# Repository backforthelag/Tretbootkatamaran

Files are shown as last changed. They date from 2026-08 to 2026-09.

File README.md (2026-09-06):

# Tretbootkatamaran
Dieses Konstruktionsprojekt beinhaltet einen nicht vollständiges Model eines Tretbootkatamaranes. Bis auf die Sitze ist alles in Eigenfertigung erfolgt. Teils gibt es Probleme beim öffnen von Baugruppen, diese werden zukünftig noch behoben. Das öffnen ist zurzeit nur über Inventor (AutoCAD) möglich.

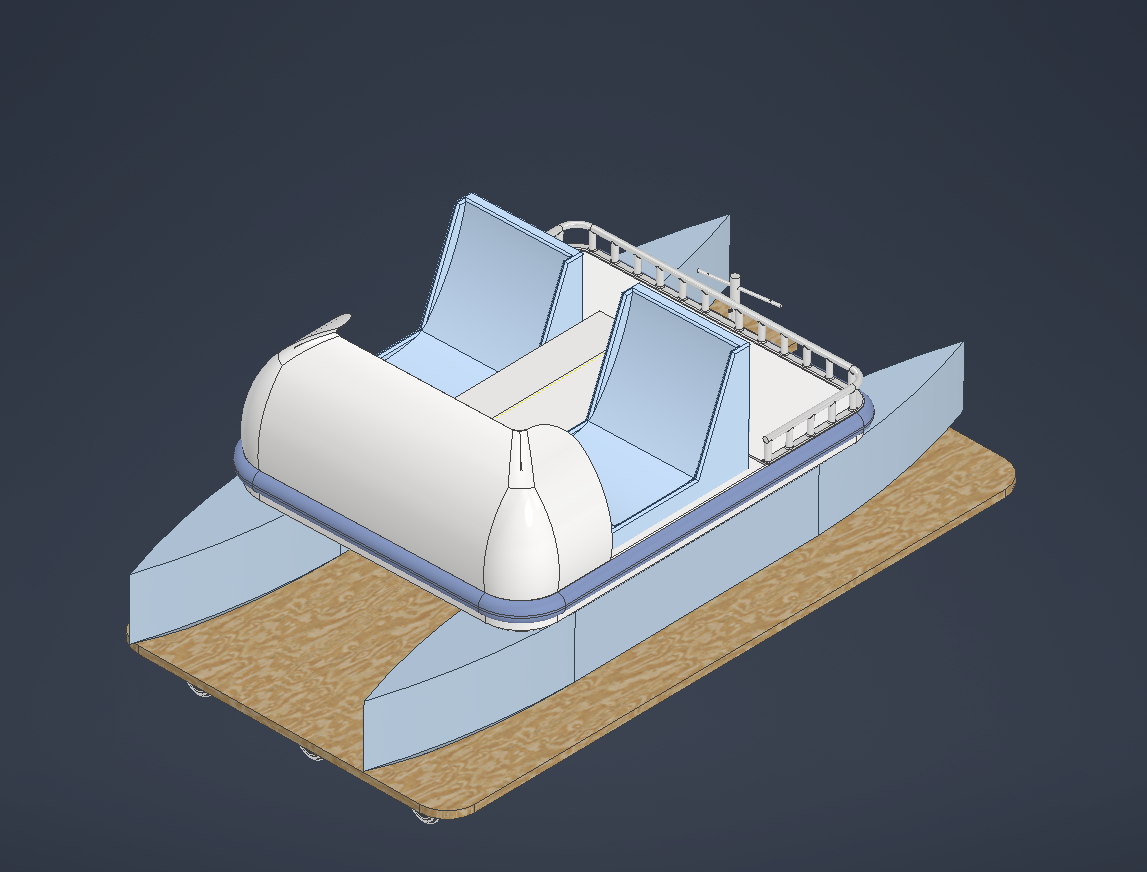
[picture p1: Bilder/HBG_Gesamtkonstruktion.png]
Bild: Hauptbaugruppe Tretbotkatamaran und Transportwagen


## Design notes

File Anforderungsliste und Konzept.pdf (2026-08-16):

### 1 A.Bunte

Bedienung

Lenkung über Schrauben, Lenkrad, Seilzug

## TretBoot-Katamaran

| Anforderungen
Kategorie | Bezeichnung der Eigenschaften | Quantitäts-wert | Qualitätswert | F/ W
Funktion | Transport von maximal 2 Personen über gemässigte Gewässer
Geometrie | Größe Höhe Breite Länge | 2,8qm <0,50m <1,6m <3,5m | Orientierung an Handelsüblichen Tretbooten, 2 Sitze symmetrisch nach vorne ausgerichtet | F
Kräfte | Gewichtskraft Drehmoment Pedal Drehmoment Schraube Auftriebskraft Antriebskraft | 2550N (≈260kg) 20-60Nm 20-60Nm 10-50Nm 10.954,23N 20-60Nm | Stabil, kippsicher, ausreichend Auftrieb auch bei Vollbelastung Gute Kraftübertragung vom Pedal auf den Antrieb Berechnet mit Polyethylendichte + 2 Personen à 70 kg | F
Kinematik | Bewegungsart Geschwindigkeit Beschleunigung | 5-10kmh | Schwimmen abhängig von Pedalkraft abhängig von der Pedalkraft | F
Energie | Leistung Reibung Wirkungsgrad | | abhängig vom Gesamtgewicht | F
Stoff | Schiffschraube Welle Pedal Außenhülle Sitze | 1 1-3 4 2 2 | leicht, groß, korrosionsbeständig recyclingfähig, Kummi Polyethyl (Standartkunststoff) Polyethylen | F
Signal | Signalform | | Navigationslichter, | F
Sicherheit | Sitz Halterung | 2 4 | rutschfest, stabile Sitzplätze kippstabil auch bei Gewichtsverlagerung | F
KT | Anforderungsliste | F = Forderung W = Wunsch
Auftrags-Nr.: | Projekt | Bearbeiter:

Ergonomie Beleuchtung Form
LED-Leuchte an der Front

### 2 parallele Rümpfe, verbunden durch Deck

F

Fertigung | Fertigungsverfahren Qualitäten Toleranzern | | Rotationssinter-Verfahren (PE-Granulat) | F
Kontrolle | Mess-und Prüfmöglichkeiten | | Prüfung von Materialermüdung, Dichtungen; Boot stabilisiert sich nach Slippen selbst | F
Montage | Vorschriftren Zusammenbau Aufbau | | gemäß Standards, sicherer Aufbau | F
Transport | Größe Gewicht Hilfsmittel | 0,5mx1,6mx3,5m 120Kg | Zugstange und Interrollen am Rumpf | F
Gebrauch | Geräuschentwicklung Einsatzort Verschleiß | <20db | abhängig von Geschwindigkeit nur für gemäßigte Gewässer Abnutzung an Rumpf und Kraftübertragungsteilen | F
Instandhaltung | Wartungsintervalle Reperatur Zeitbedarf | 30 Tage 2min | Überprüfung vor jedem Gebrauch Reparatur bei sichtbaren Schäden | F
Recycling | Wiederverwendung Verwertung Entsorgung | | Kunststoff kann geschreddert und als PE-Granulat wiederverwendet werden Fachgerechte Entsorgung, Recyclinghof | F
Kosten | Herstellerkosten Werkzeugkosten | <1000€ | kosteneffizient durch Standardteile und serientaugliche Fertigung | F
Termin | Liefertermin Projektplan | | Liefertermin nicht geplant, nur praktische Planung und theoretische Durchführung | F

# | Teilfunktionen

1 Muskelkraft in Drehmoment umwandeln 2 Drehmoment in Vortrieb wandeln 3 Richtung ändern 4 Personen aufnehmen 5 Trettboot transportieren 6 Trettboot montierten 7 Trettboot demontierten 8 Sicherheit gewährleisten 9 Befestigung zum sichern der Passagiere 10 Beleuchtung bereitstellen 11 Kollision lindern

Muskelkraft in Drehmoment umwandeln

Bewegungsenergie

Belastung

Verstellweg

Teile bewegen

Übertragung Kräfte

Rotationsenergie

Bewegung von Teilen

Rotationsbewegung

Drehmoment in Vortrieb wandeln

Rotationsenergie

Übertragung

Verstellweg

Teile bewegen

Übertragung Kräfte

hydrostatische Energie

Bewegung in Antriebsglied

Energie Antrieb

Richtung ändern

Kraftsteuerung

Übertragung

Verstellweg

Ruderstellung

Übertragung Kräfte

Bewegungsenergie

Bewegung Steuerungsstellglied Richtung

Energie Antrieb

Personen aufnehmen

Gewichtskraft

Verteilung

Verstellweg

Kraftübertragung
auf Material
Übertragung Kräfte

Druckenergie

Boot stabil

Halteenergie

Bootmaterial leitet Kräfte in Wasser

Trettboot transportieren

Zugkraft
Energie
wandeln

Steuerimpuls

Boot transportieren

Stoff leiten

Bewegungsenergie

Boot stabil

Ausführung der Bewegung

Bootmaterial leitet Kräfte in Wasser

Trettboot montieren

Bewegungsenergie
Energie
wandeln

Verbindung von
Bauteilen
Verknüpfung

Bewegungsenergie

Verbund aus Teilen

Boot

Trettboot demontieren

Körperkraft/ Werkzeugkraft

Hebekraft/ Stützkraft

Demontageanleitung

Trettboot montiert

Druckenergie / Reibungsenergie

Demontierte Komponenten

Demontage abgeschlossen

Verbindungen gelöst

Sicherheit gewährleisten

Handkraft / Muskelkraft

Handlungsanweisung

Gefahrensituation erkannt

Druckenergie / Halteenergie

Sicherheit gewährleistet

Sicherheitsbestätigung

Befestigung zum sichern der Passagiere

Handkraft

Sicherheitsvorgaben

Passagiere

Druckenergie / Halteenergie

gesicherte Passagiere

Sicherheitsbedingung erfüllt

Bauteile für Befestigung | geschlossene Befestigung

Beleuchtung bereitstellen

elektrische Energie

Signalfluss

Energie wandeln

Lichtwellen

Beleuchtung bereitgestellt

optischer energieflusss (Licht)

Kollision lindern

kinetische Energie

Kollision erkannt

Dämpfung gewährleisten

potentielle Enrgie

dämpfendes System

Risiko befälltigung

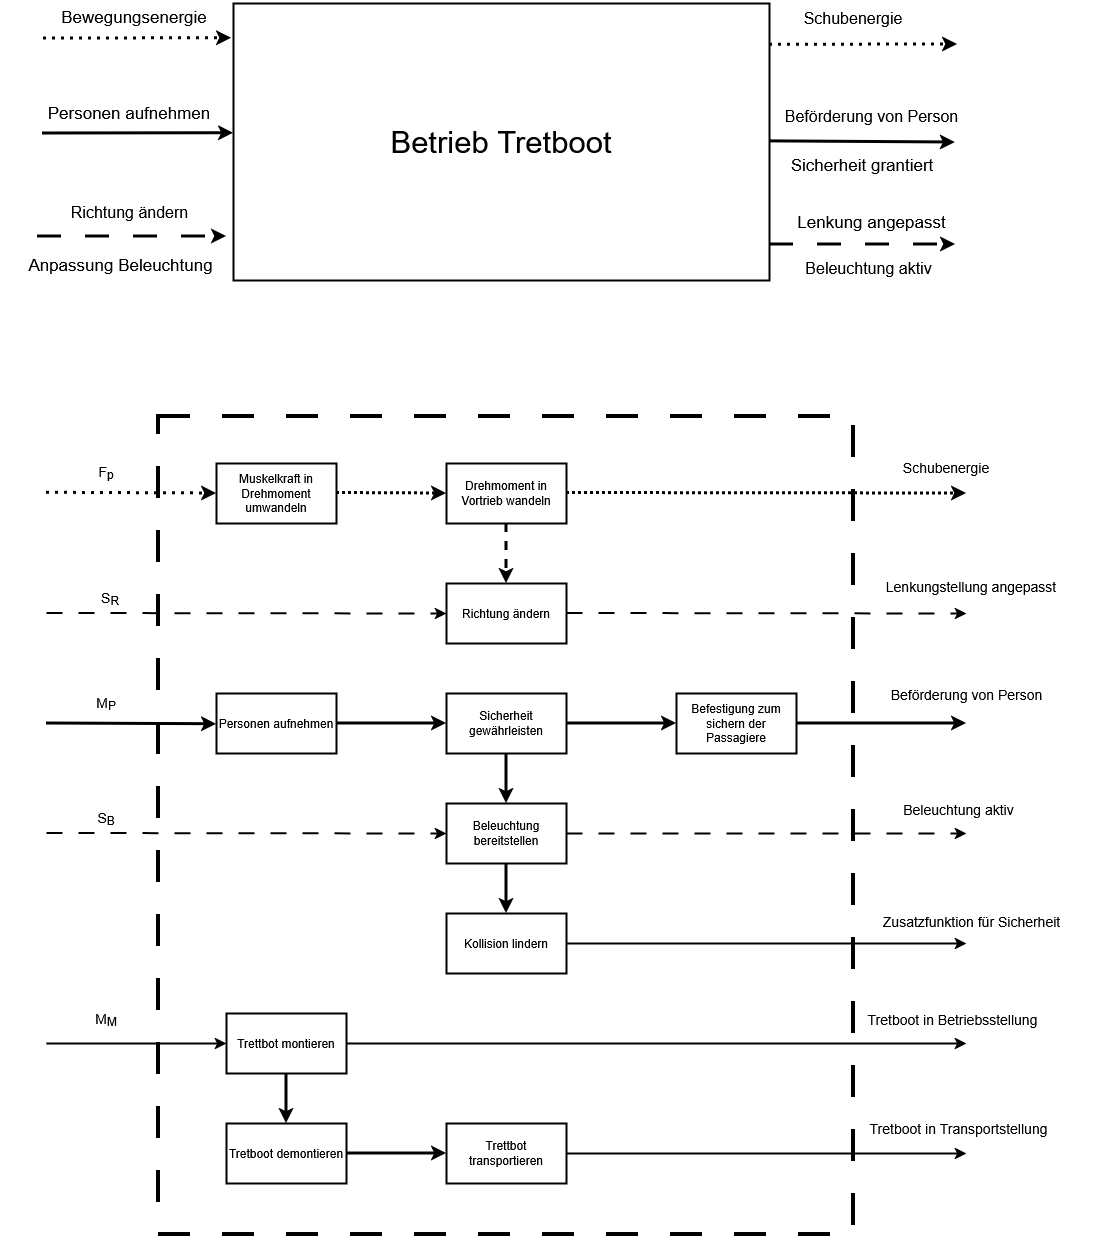
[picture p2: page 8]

Lösungen Teilfunktionen | 1 | 2 | 3 | 4
1 | Muskelkraft in Drehmoment umwandeln
2 | Drehmoment in Vortrieb wandeln | Zahnriemen | Rollenkette mit Spannrolle | Kardanwelle mit Kreuzgelenk | Riemenband
Kurbelpedal | Linear-Pedal mit Rückstellfeder | Pedalo-Mechanik | Doppelkurbel
3 | Richtung ändern | Ruderblatt mit Seilzuglenkung | Bugstrahler | Doppelruder über Stange | Strömungsleitblech hinter Propeller
4 | Personen aufnehmen | Sitzschale | Sitzschale mit Sitzkonsole(Schienenführung) Aluminiumbank mit Polster | Klappsitz mit Verrieglung
5 | Trettboot transportieren | Tragegriffe an den Seiten | Steckbare Transportrollen | Zugstange-Inter Rollen | 「 Rumpf-Rollen
6 | Trettboot montierten | Scharnier | Schnellspanner Exzenterklemme | Klappmechanismus Faltmodul | Verschraubung Flügelmuttern
7 | Trettboot demontierten | Splint Sicherung | Schiebeprofil | Bolzen mit Kontermutter | Scherengelenk
8 | Sicherheit gewährleisten | Rutschfeste Bodenmatte | Polster | Handlauf | Gummi Pedale
9 | Befestigung zum sichern der Passagiere
10 | Beleuchtung bereitstellen
Henkel | Boothandläufe | Reeling | Einstiegsleiter
LED-Positionslichter | Toplicht LED | Reflektorstreifen | LED-Leisten
10 | Kollision lindern | Scheuerleiste | Stoßfänger | Fender | Gummi Metall Puffer an Seiten

## Rot : Variante 1 Grün: Variante 2 Blau : Variante 3

、

Lösungen Teilfunktionen | 1 | 2 | 3 | 4
1 | Muskelkraft in Drehmoment umwandeln
2 | Drehmoment in Vortrieb wandeln
3 Richtung ändern | | | | | Strömungsleitblech hinter Propeller
4 | Personen aufnehmen | Sitzschale
5 | Trettboot transportieren | Tragegriffe
6 | Trettboot montierten | | | Klappmechanismus Faltmodul
7 | Trettboot demontierten | | | Bolzen mit Kontermutter
8 | Sicherheit gewährleisten | Rutschfeste Bodenmatte | Polster | Handlauf | Gummi Pedale
9 | Befestigung zum sichern der Passagiere | | | | Einstiegsleiter
10 | Beleuchtung bereitstellen
11 Kollision lindern | | | | | Gummi Metall Puffer an Seiten

Bewertungskriterien Eigenschaftsgrößen Nr. Gew. Einh. | Variante V Wert Gew. Wert | Variante V Wert Gew. Wert | Variante V Wert Gew.Wert
1 Tretboot ermöglicht Personentransport | | 0,05 zulässige Nutzlast | | kg | 5 | 0,25 | 3 | 0,15 | 4 | 0,2
2 Kapazität max. 2 personen | | 0,04 max. Personenzahl | | | 4 | 0,16 | 3 | 0,12 | 2 | 0,08
3 gute Manövrierbarkeit | | 0,12 min. Wenderadius | | | 3 | 0,36 | 2 | 0,24 | 2 | 0,24
4 Geschwindigkeit ausreichend für Freizeitbetrieb | | 0,06 Geschwindigkeit | | Kmh | 5 | 0,05 | 6 | 0,36 | 4 | 0,24
5 leichte Bedienbarkeit | | 0,12 erforderliche Tretkraft | | N | 6 | 0,14 | 3 | 0,36 | 1 | 0,12
6 gute Kraftübertragung | | 0,06 Wirkungsgrad | | % | 3 | 0,18 | 5 | 0,3 | 3 | 0,18
7 katamaranähnlicher Aufbau | | 0,05 Anzahl/ Abstand der Schwimmkörper Stück / m | | | 3 | 0,15 | 3 | 0,15 | 2 | 0,1
8 Wasserbeständigkeit | | 0,06 Material-Klasse | | | 5 | 0,3 | 3 | 0,18 | 4 | 0,24
9 Haltepunkte / Griffmöglichkeiten | | 0,04 Anzahl der Griffe | | Stück | 4 | 0,16 | 4 | 0,16 | 5 | 0,2
10 Höhe <0,5m | | 0,03 Gesamthöhe | | m | 3 | 0,09 | 3 | 0,09 | 1 | 0,03
11 Breite <1,6m | | 0,03 Gesamtbreite | | m | 3 | 0,09 | 3 | 0,09 | 3 | 0,09
12 Länge <3,5m | | 0,03 Gesamtlänge | | m | 3 | 0,09 | 2 | 0,06 | 3 | 0,09
13 Gewicht <140kg | | 0,05 Eigengewicht | | kg | 5 | 0,25 | 2 | 0,1 | 5 | 0,25
14 Betrieb auf Binnengewässern | | 0,05 Einsatzzweck-Klassifizierung | | | 4 | 0,2 | 3 | 0,15 | 4 | 0,2
15 Transport mit öffentlichen Verkehrsmitteln | | 0,12 max. Packmaße(LxBxH) | | m | 2 | 0,24 | 1 | 0,12 | 1 | 0,12
16 Produktionskosten <1000€ | | 0,09 Herstellungskosten, Stück | | € | 4 | 0,36 | 2 | 0,18 | 2 | 0,18
Summe | 1 | 3,07 | 2,81 | 2,56

Nutzwertanalyse Pkt. Bedeutung | Richtlinie VDI 2225 Pkt. Bedeutung
0 | absolut unbrauchbare Lösung | 0 | unbefriedigend
1 | sehr mangelhafte Lösung
2 | schwache Lösung | 1 | gerade noch tragbar
3 | tragbare Lösung
4 | ausreichende Lösung | 2 | ausreichend
5 | befriedigende Lösung
6 | gute Lösung mit geringen Mängeln | 3 | gut
7 | gute Lösung
8 | sehr gute Lösung | 4 | sehr gut (ideal)
9 | über die Zielvorstellung hinausgehende Lösung
10 | Ideallösung

Werteskala

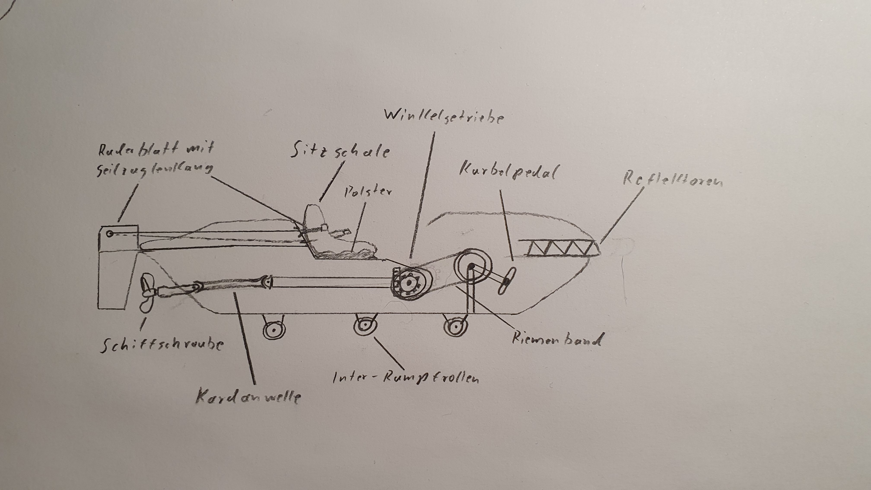
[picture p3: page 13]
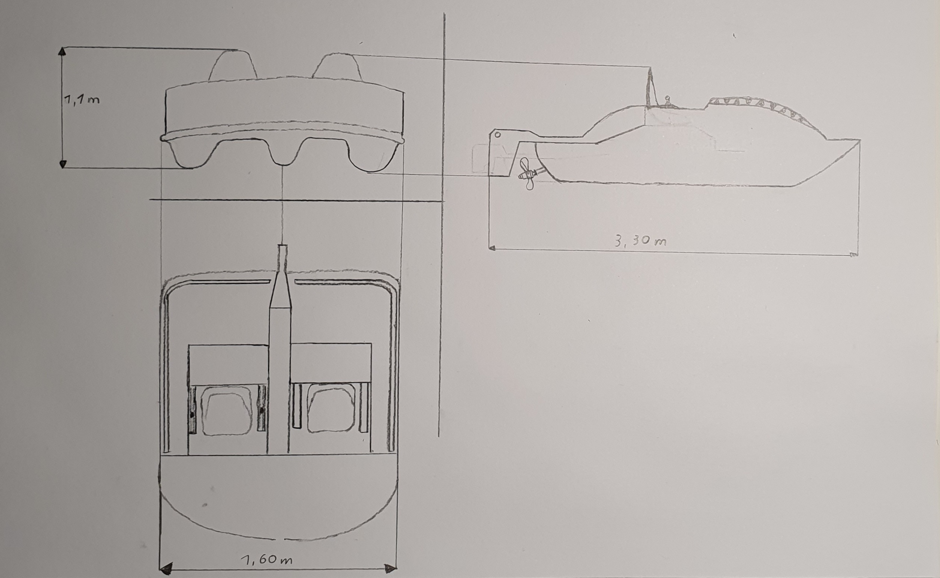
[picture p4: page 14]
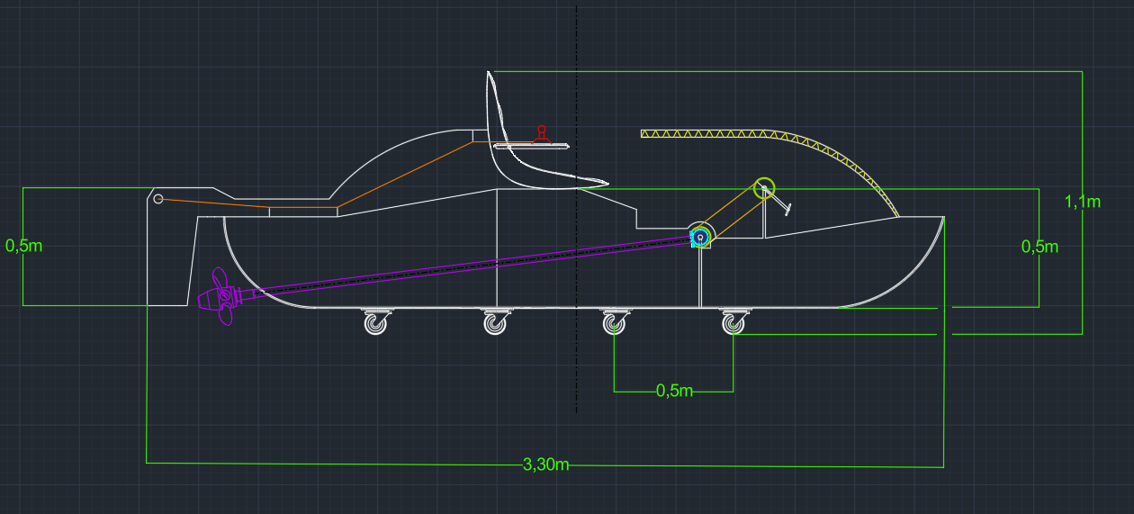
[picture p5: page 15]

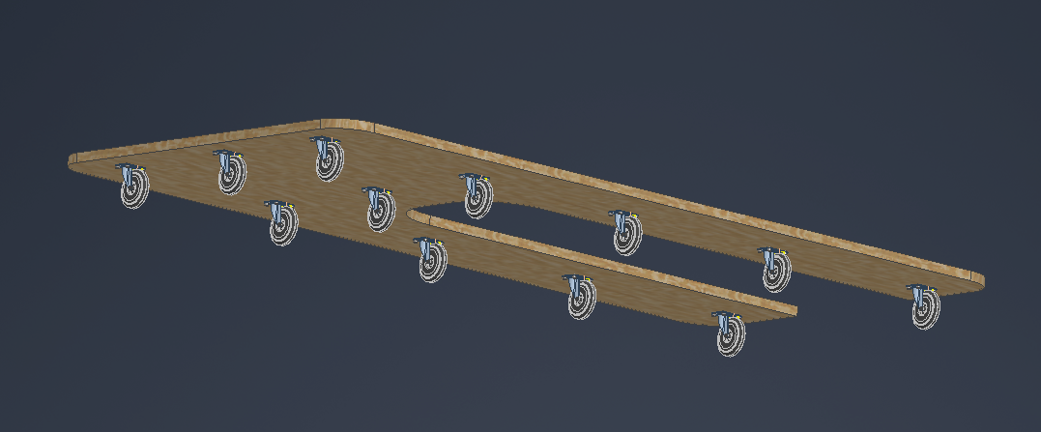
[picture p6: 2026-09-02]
Bilder/Transportwagen.png

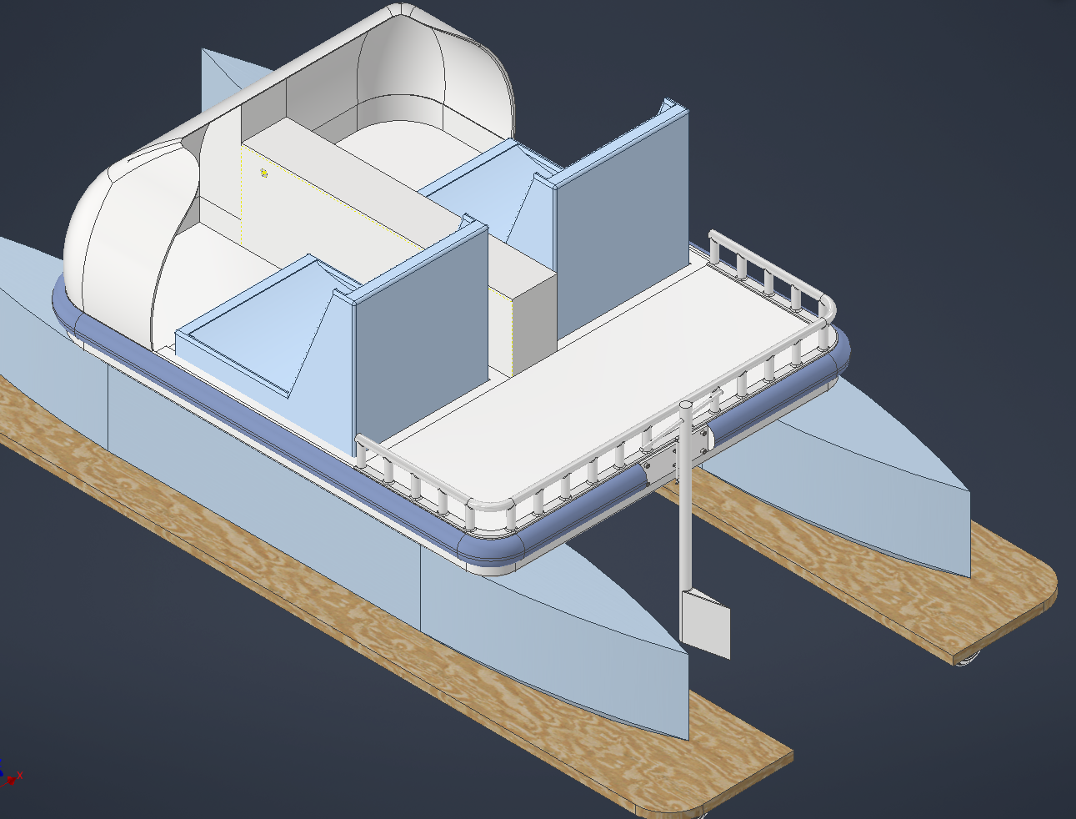
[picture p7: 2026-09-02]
Bilder/HBG_Rückseite.png

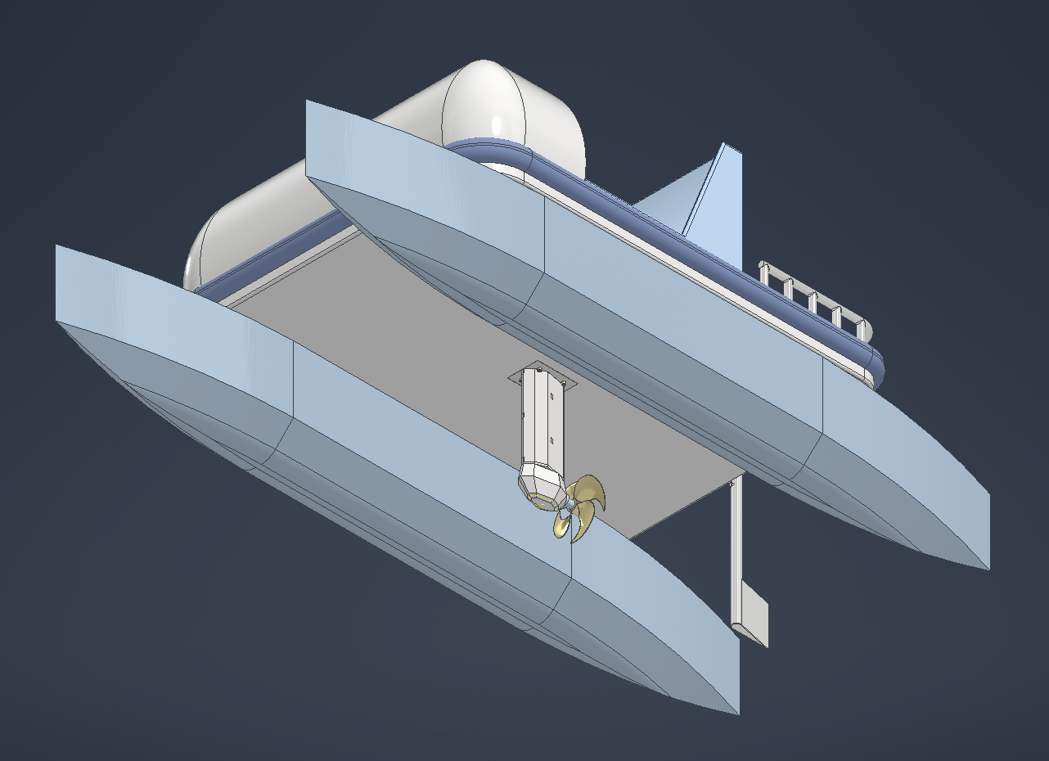
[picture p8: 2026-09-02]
Bilder/HBG_Unterseite.png

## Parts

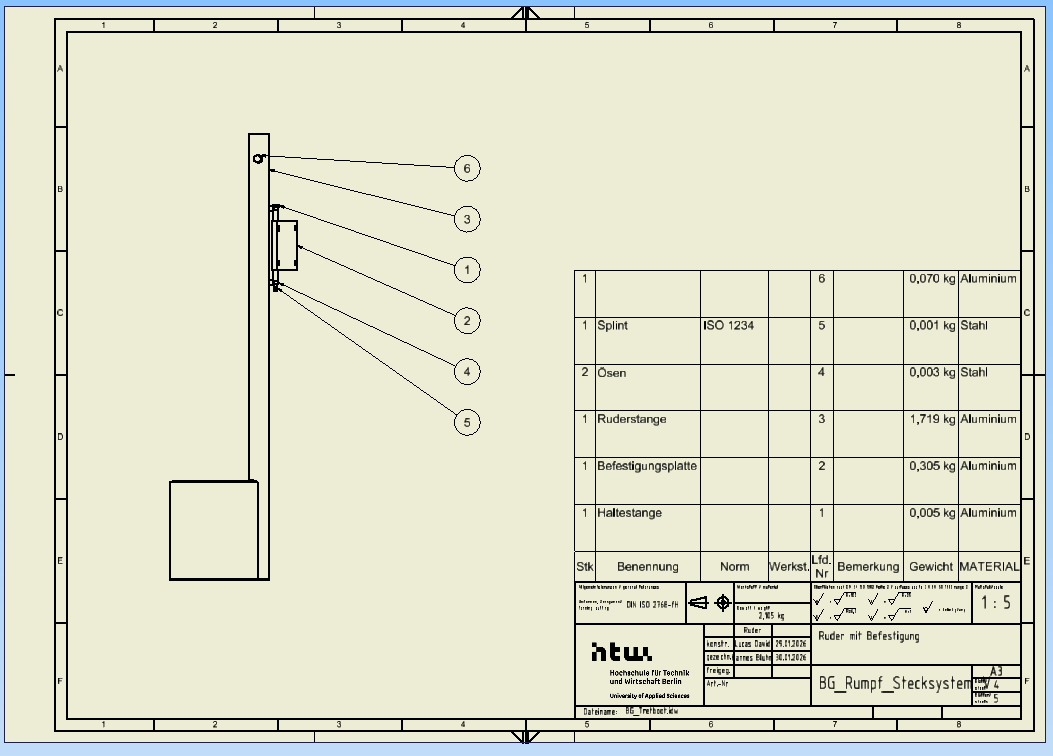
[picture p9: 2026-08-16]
Zeichnungen/Bilder Materialliste/Ruder.png

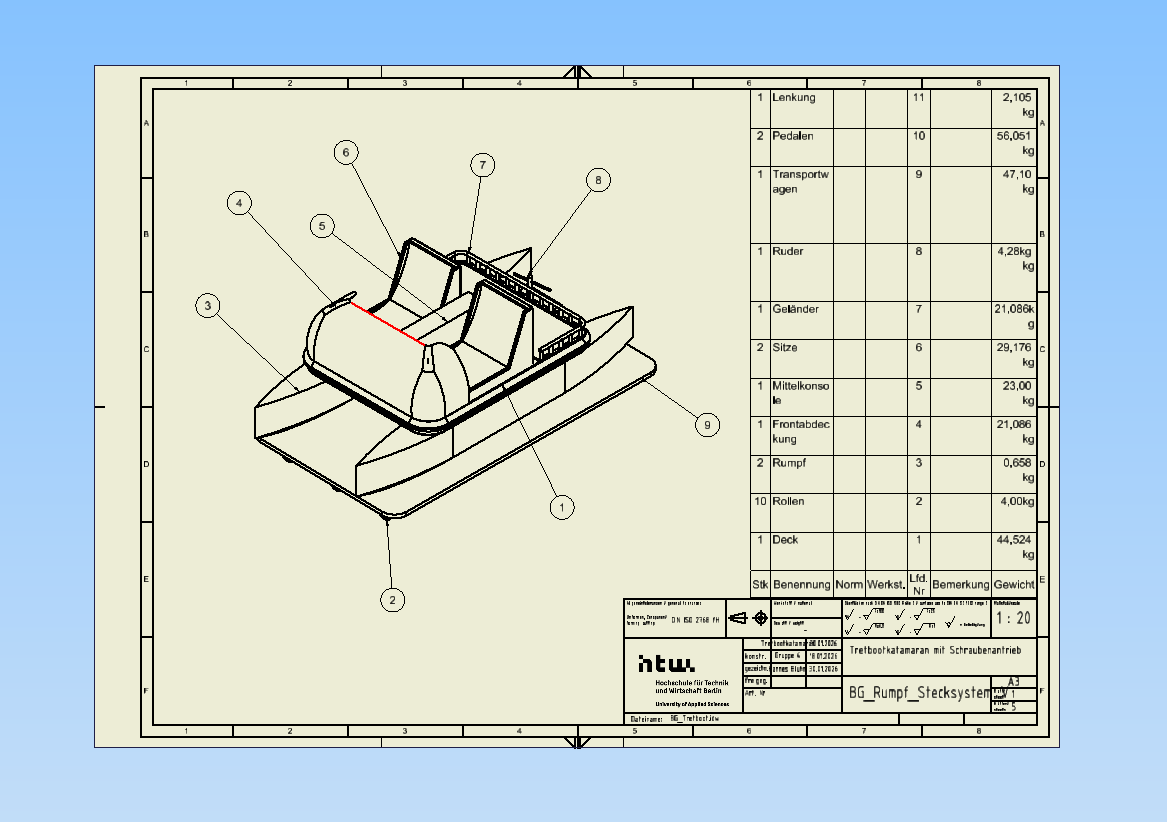
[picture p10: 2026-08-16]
Zeichnungen/Bilder Materialliste/Gesamtes_Tretboot.png

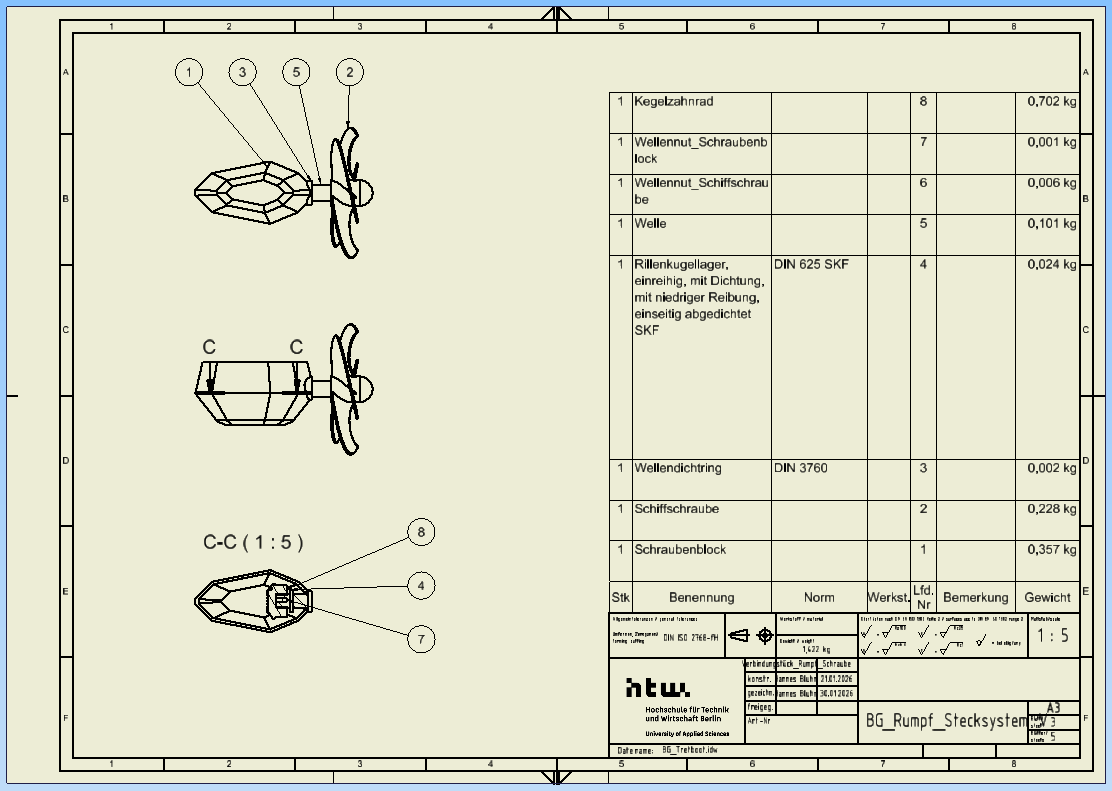
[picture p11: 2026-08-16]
Zeichnungen/Bilder Materialliste/Antrieb.png

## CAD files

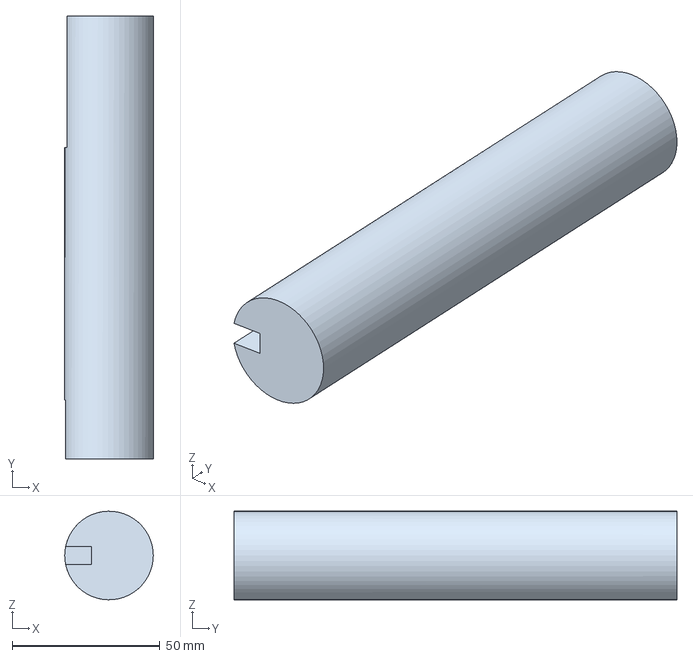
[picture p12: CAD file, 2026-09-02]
Step-Dateien/Antrieb/Welle_Schraube.stp
30.0 x 150.0 x 30.0 mm

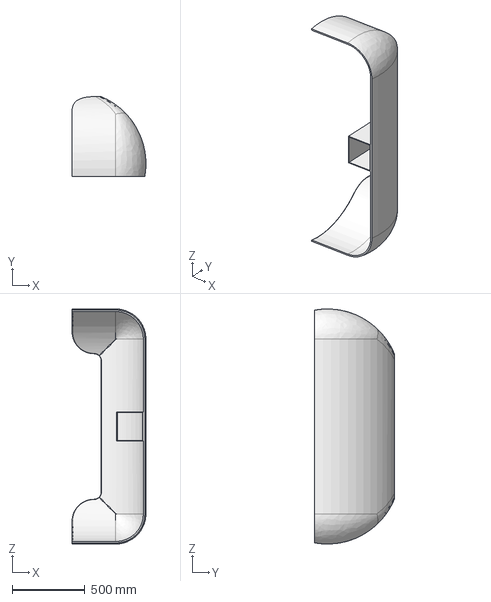
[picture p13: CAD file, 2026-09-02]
Step-Dateien/Deck/Frontabdeckung.stp
507.3 x 551.8 x 1615.1 mm

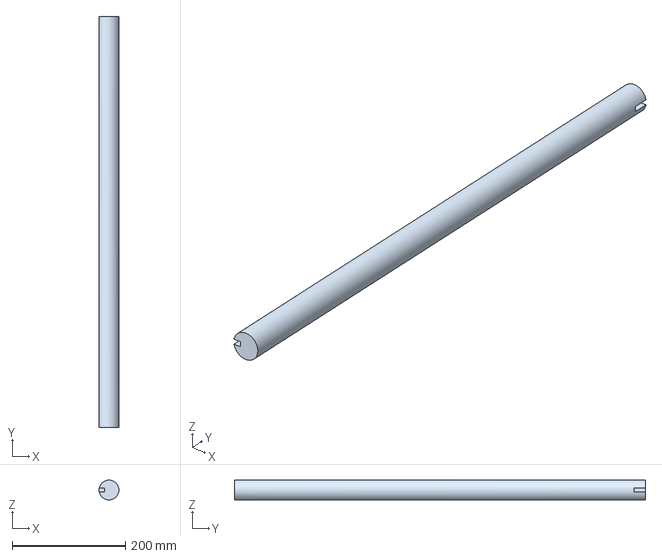
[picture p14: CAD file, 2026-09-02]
Step-Dateien/Deck_Getriebe/Welle_Deck_Getriebe.stp
35.0 x 724.3 x 35.0 mm

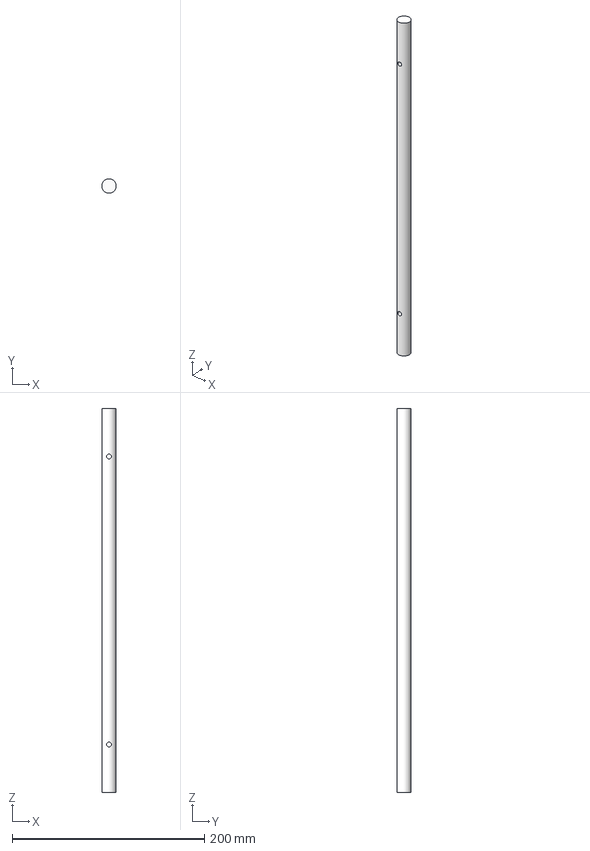
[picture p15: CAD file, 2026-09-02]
Step-Dateien/Ruder/Lenkstange.stp
15.0 x 15.0 x 400.0 mm

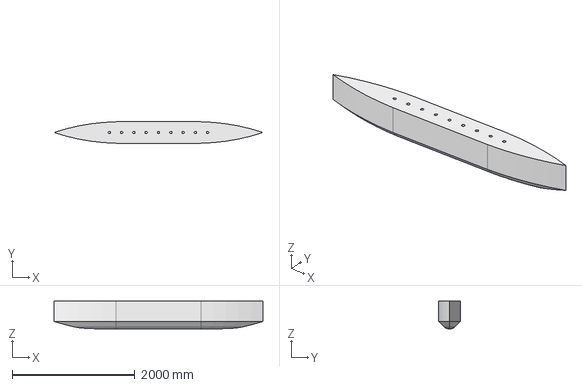
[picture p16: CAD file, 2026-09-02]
Step-Dateien/Rumpf/Außenrumpf_schnittig.stp
3400.0 x 350.0 x 450.0 mm

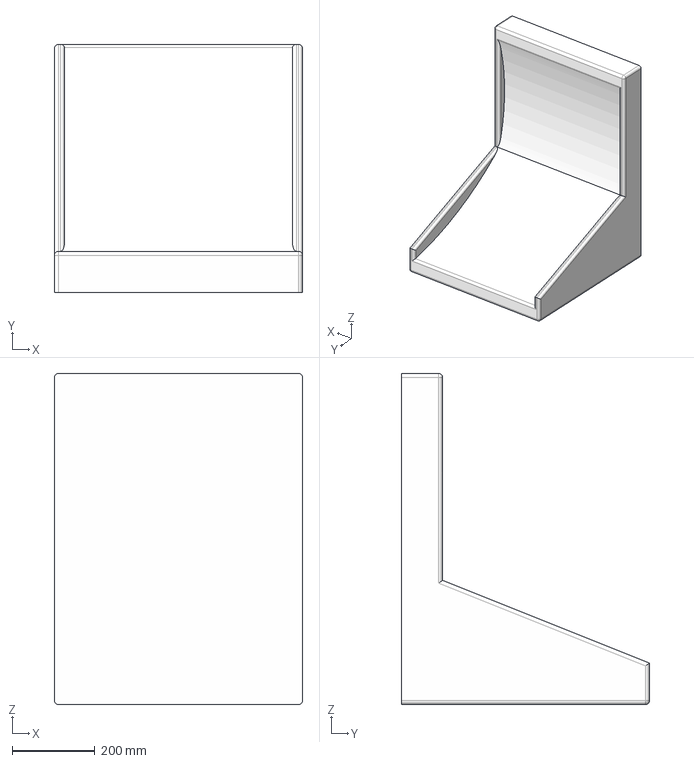
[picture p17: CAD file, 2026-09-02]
Step-Dateien/Sitz/Sitz.stp
600.0 x 600.0 x 800.0 mm

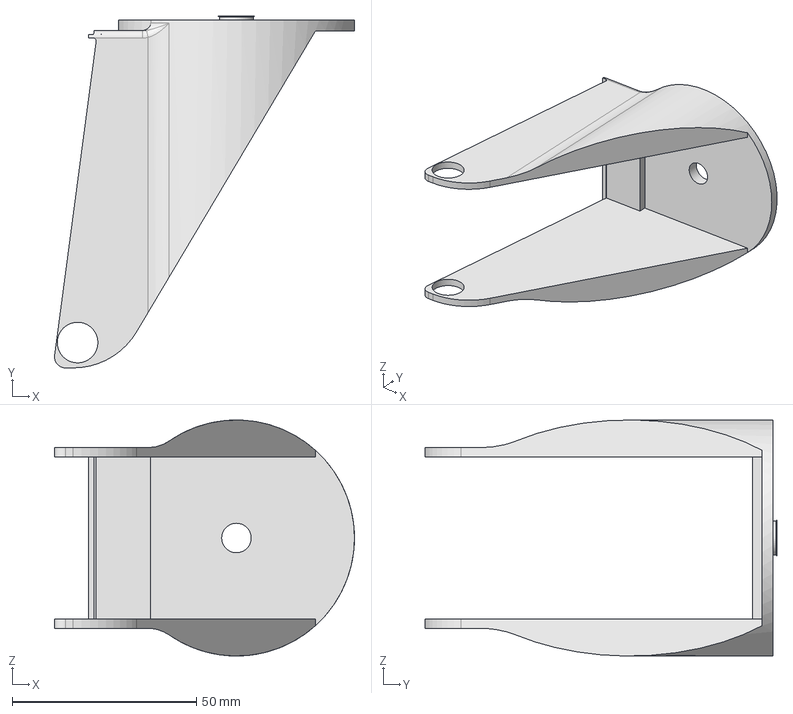
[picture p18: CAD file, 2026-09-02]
Step-Dateien/Transport/Rolle_RippenStütze.stp
81.3 x 95.4 x 64.0 mm

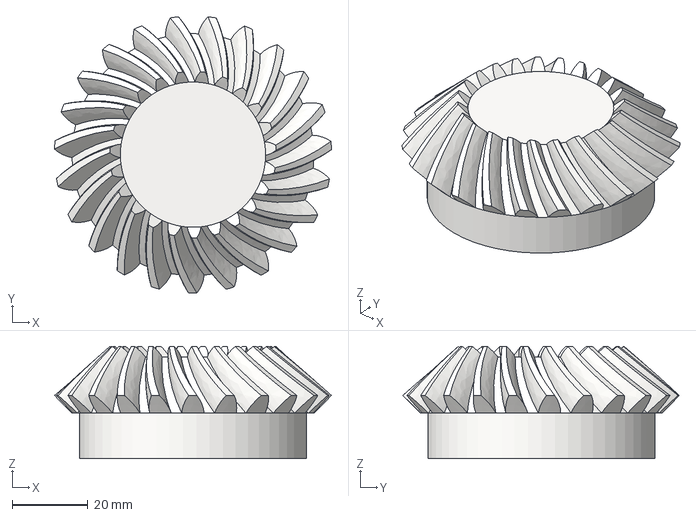
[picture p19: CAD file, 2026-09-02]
Step-Dateien/Verbindung_Deck_Antrieb/Kegelrad_20x10_01.stp
73.2 x 73.0 x 29.6 mm

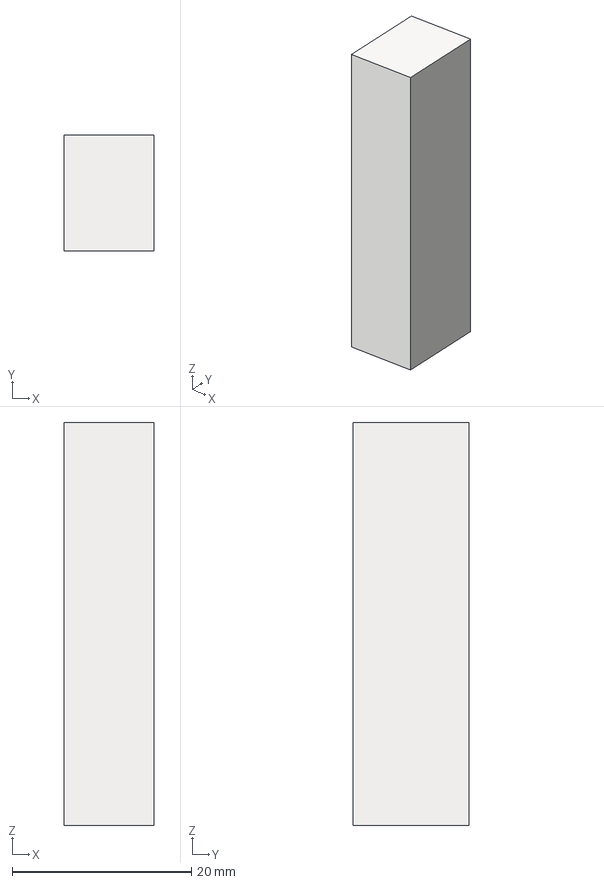
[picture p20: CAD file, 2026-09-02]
Step-Dateien/Antrieb/Wellennut_Antrieb_Propeller.stp
10.0 x 13.0 x 45.0 mm

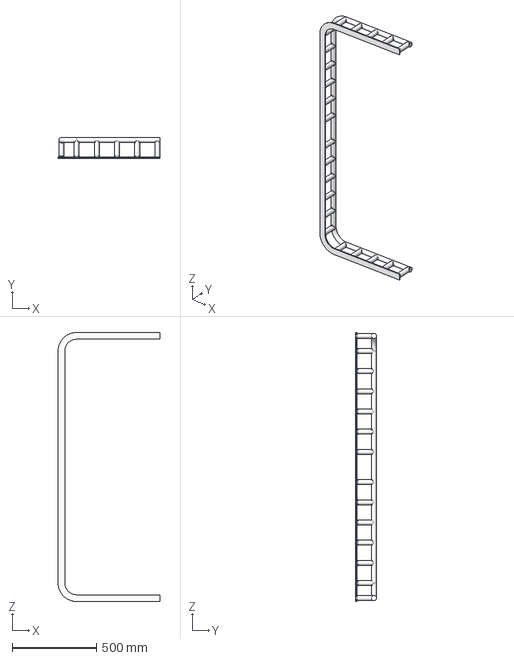
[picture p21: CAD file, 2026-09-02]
Step-Dateien/Deck/Geländer.stp
605.9 x 125.0 x 1600.0 mm

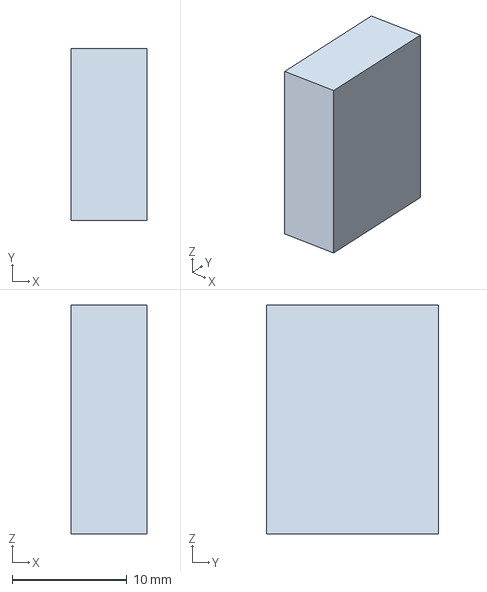
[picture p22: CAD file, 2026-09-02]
Step-Dateien/Deck_Getriebe/Wellennut.stp
6.62 x 15.0 x 20.0 mm

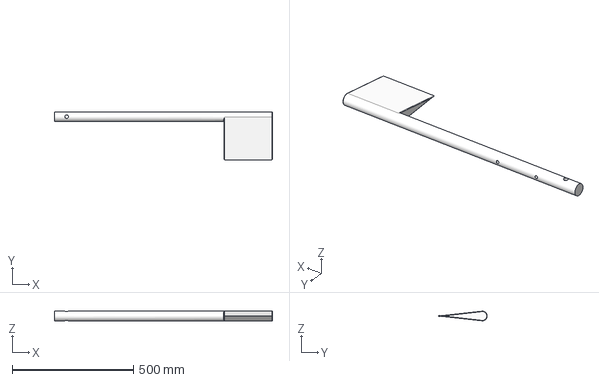
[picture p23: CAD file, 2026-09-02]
Step-Dateien/Ruder/Ruder_passende_Maße.stp
900.0 x 200.0 x 40.0 mm

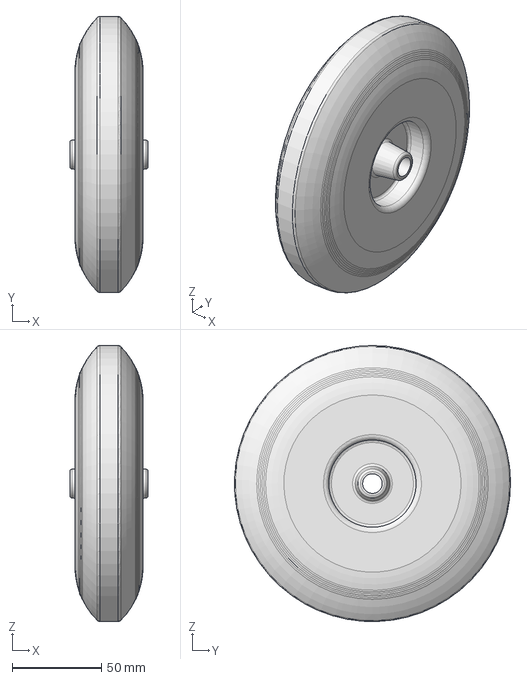
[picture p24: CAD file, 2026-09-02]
Step-Dateien/Transport/Rolle.stp
44.0 x 154.9 x 154.9 mm

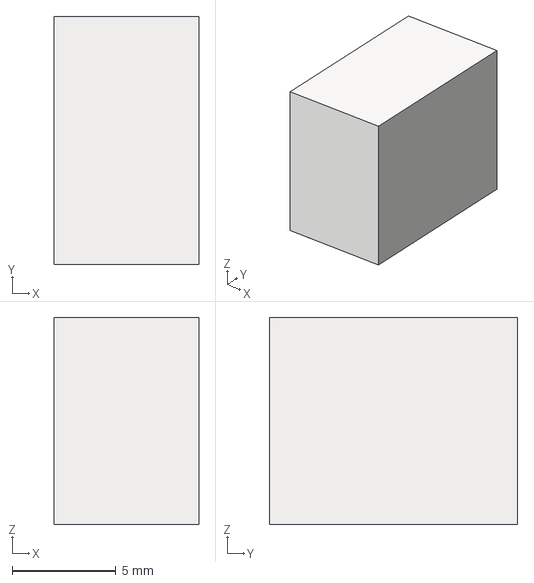
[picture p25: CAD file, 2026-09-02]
Step-Dateien/Verbindung_Deck_Antrieb/Wellennut_Verbindung_Deck_Antrieb.stp
7.00 x 12.0 x 10.0 mm

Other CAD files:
Step-Dateien/Antrieb/Propeller_groß.stp
Step-Dateien/Deck/Verbindungsstück_Rumpf_Stecksystem.stp
Step-Dateien/Deck_Getriebe/Mittelkonsole.stp
Step-Dateien/Ruder/Plattform_mit_Rohr_für_Montierung.stp
Antrieb/BG_Schiffschraube.iam
Antrieb/Kegelrad01.ipt
Antrieb/OldVersions/BG_Schiffschraube.0010.iam
Antrieb/Propeller.ipt
Antrieb/Propeller_groß.ipt
Antrieb/Schrauben_Block.ipt
Antrieb/Schrauben_Strang.ipt
Antrieb/Welle_Schraube.ipt
Antrieb/Wellennut_Antrieb_Propeller.ipt
Antrieb/Wellennut_Antrieb_Schrauben_Block.ipt
Deck/Frontabdeckung.ipt
Deck/Geländer.ipt
Deck/Verbindungsstück_Rumpf_Stecksystem.ipt
Deck_Getriebe/BG_Kegelräder.iam
Deck_Getriebe/BG_Kegelzahnräder.iam
Deck_Getriebe/BG_Mittelkonsole.iam
Deck_Getriebe/Kegelrad01.ipt
Deck_Getriebe/Kegelrad02.ipt
Deck_Getriebe/Mittelkonsole.ipt
Deck_Getriebe/Neu Kegelrad_Version01.ipt
Deck_Getriebe/Neu Kegelrad_Version02.ipt
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

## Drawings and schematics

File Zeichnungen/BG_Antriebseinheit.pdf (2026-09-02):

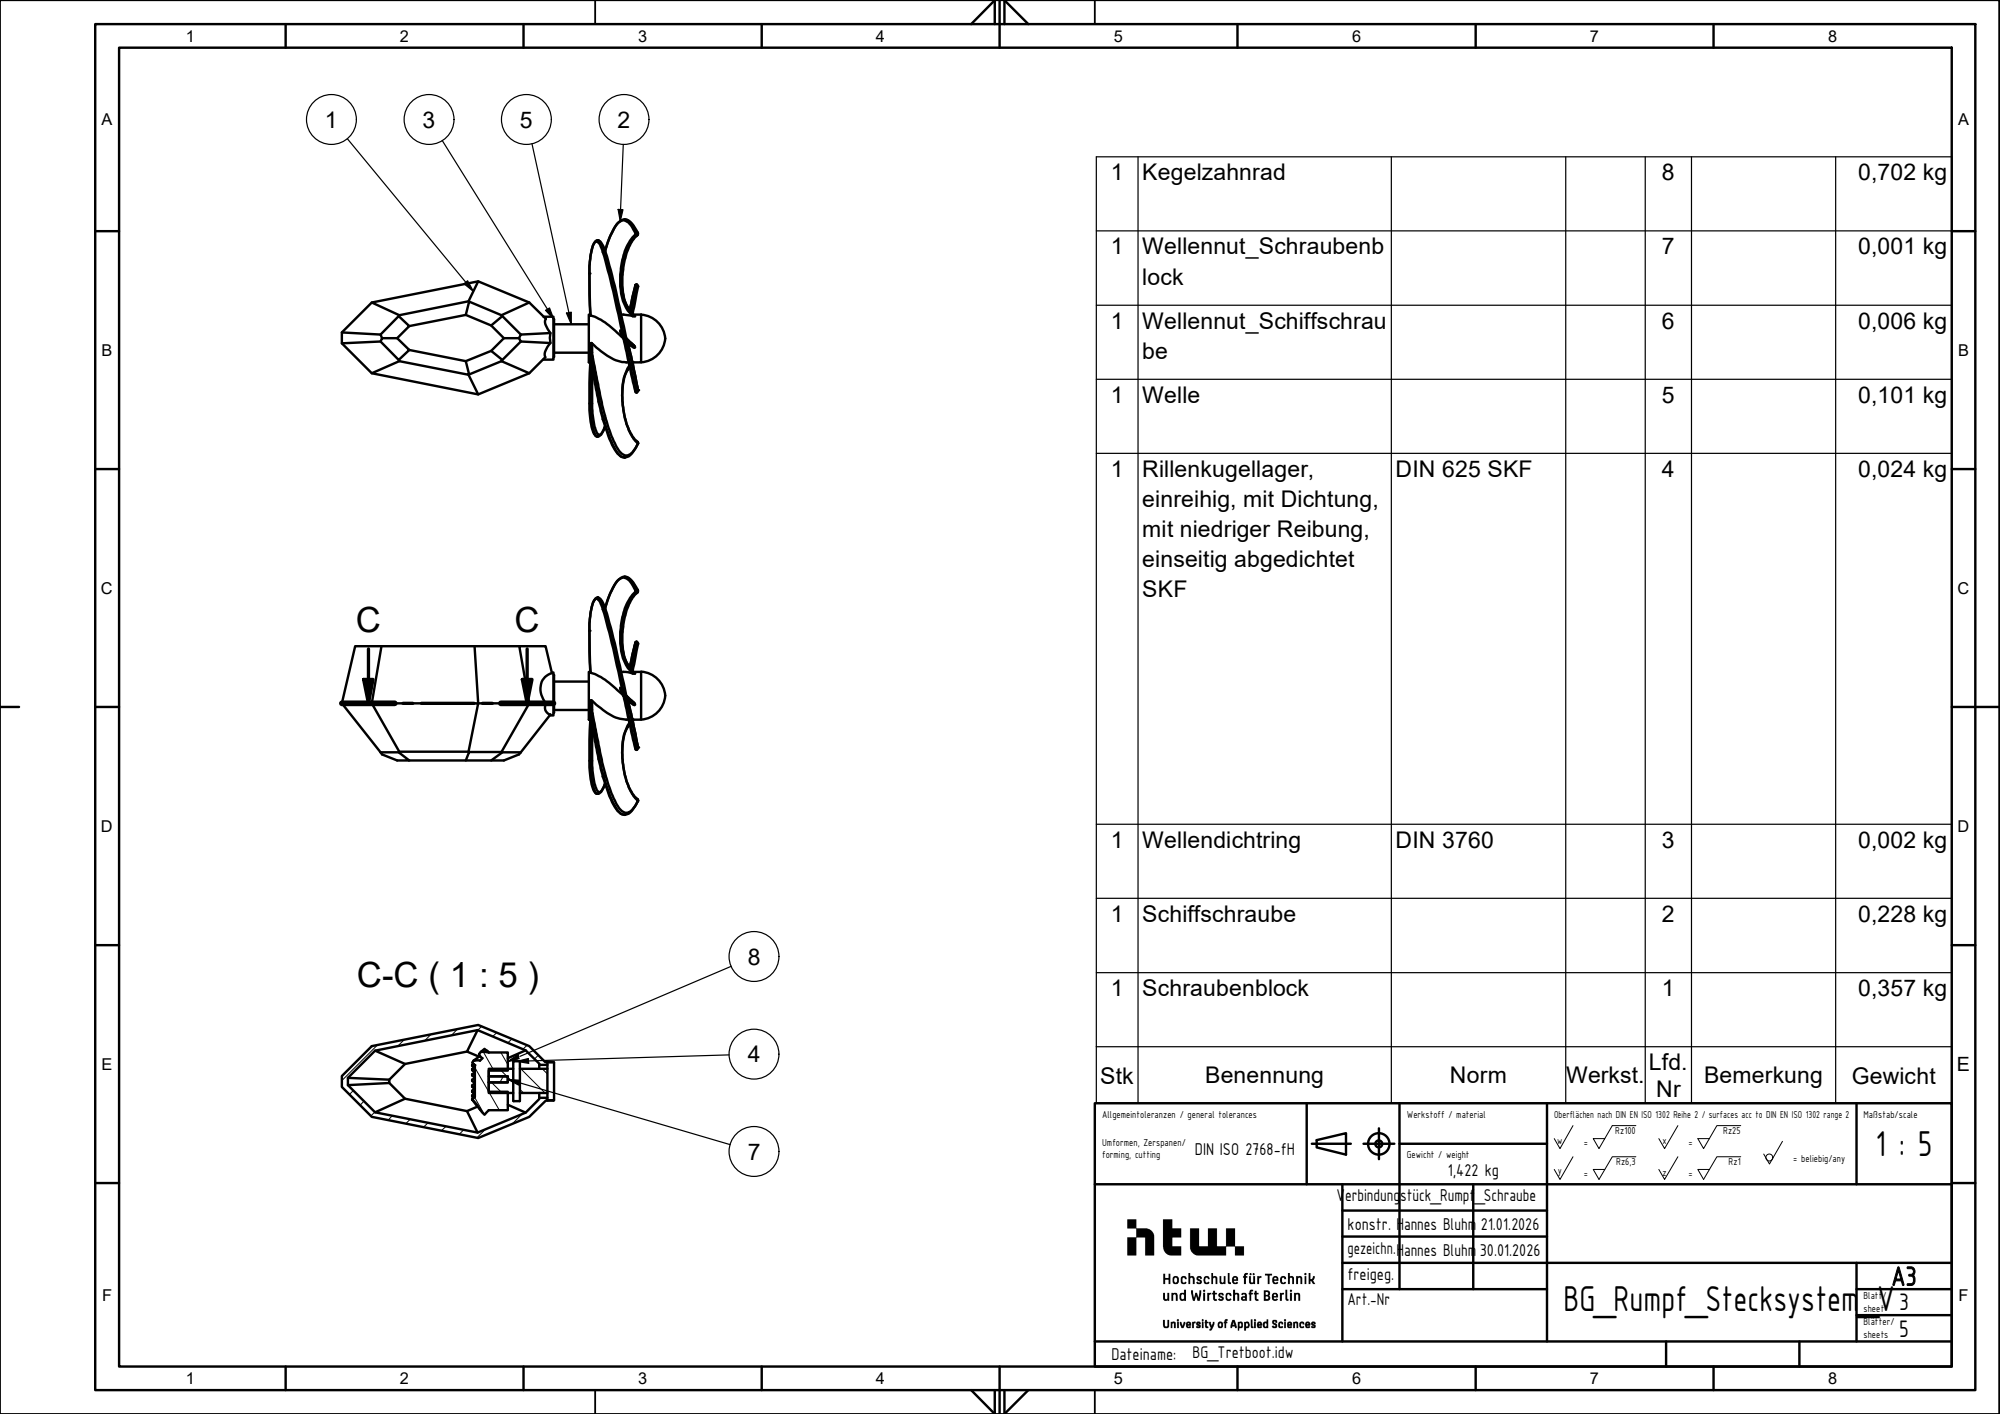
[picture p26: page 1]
Gewicht / weight 1,422 kg; Dateiname: BG_Tretboot.idw

1 | Kegelzahnrad | | | 8 | | 0,702 kg

1 | Wellennut_Schraubenb lock | | | 7 | | 0,001 kg

1 | Wellennut_Schiffschrau be | | | 6 | | 0,006 kg

1 | Welle | | | 5 | | 0,101 kg

1 | Rillenkugellager, einreihig, mit Dichtung, mit niedriger Reibung, einseitig abgedichtet SKF | DIN 625 SKF | | 4 | | 0,024 kg

1 | Wellendichtring | DIN 3760 | | 3 | | 0,002 kg

1 | Schiffschraube | | | 2 | | 0,228 kg

1 | Schraubenblock | | | 1 | | 0,357 kg

Stk | Benennung | Norm | Werkst. | Lfd. Nr | Bemerkung | Gewicht

Allgemeintoleranzen / general tolerances Umformen, Zerspanen/ forming, cutting DIN ISO 2768-fH | | Werkstoff / material | Oberflächen nach DIN EN ISO 1302 Reihe 2 / surfaces acc to DIN EN ISO 1302 range 2 Rz100 Rz25 w = x = = beliebig/any Rz6,3 Rz1 y = z = | Maßstab/scale 1 : 5

Verbindungstück_Rumpf_Schraube
konstr. | Hannes Bluhm | 21.01.2026
gezeichn. | Hannes Bluhm 30.01.2026
freigeg. | | | BG_Rumpf_Stecksystem_V | A3
Art.-Nr | | | | Blatt/ 3 sheet

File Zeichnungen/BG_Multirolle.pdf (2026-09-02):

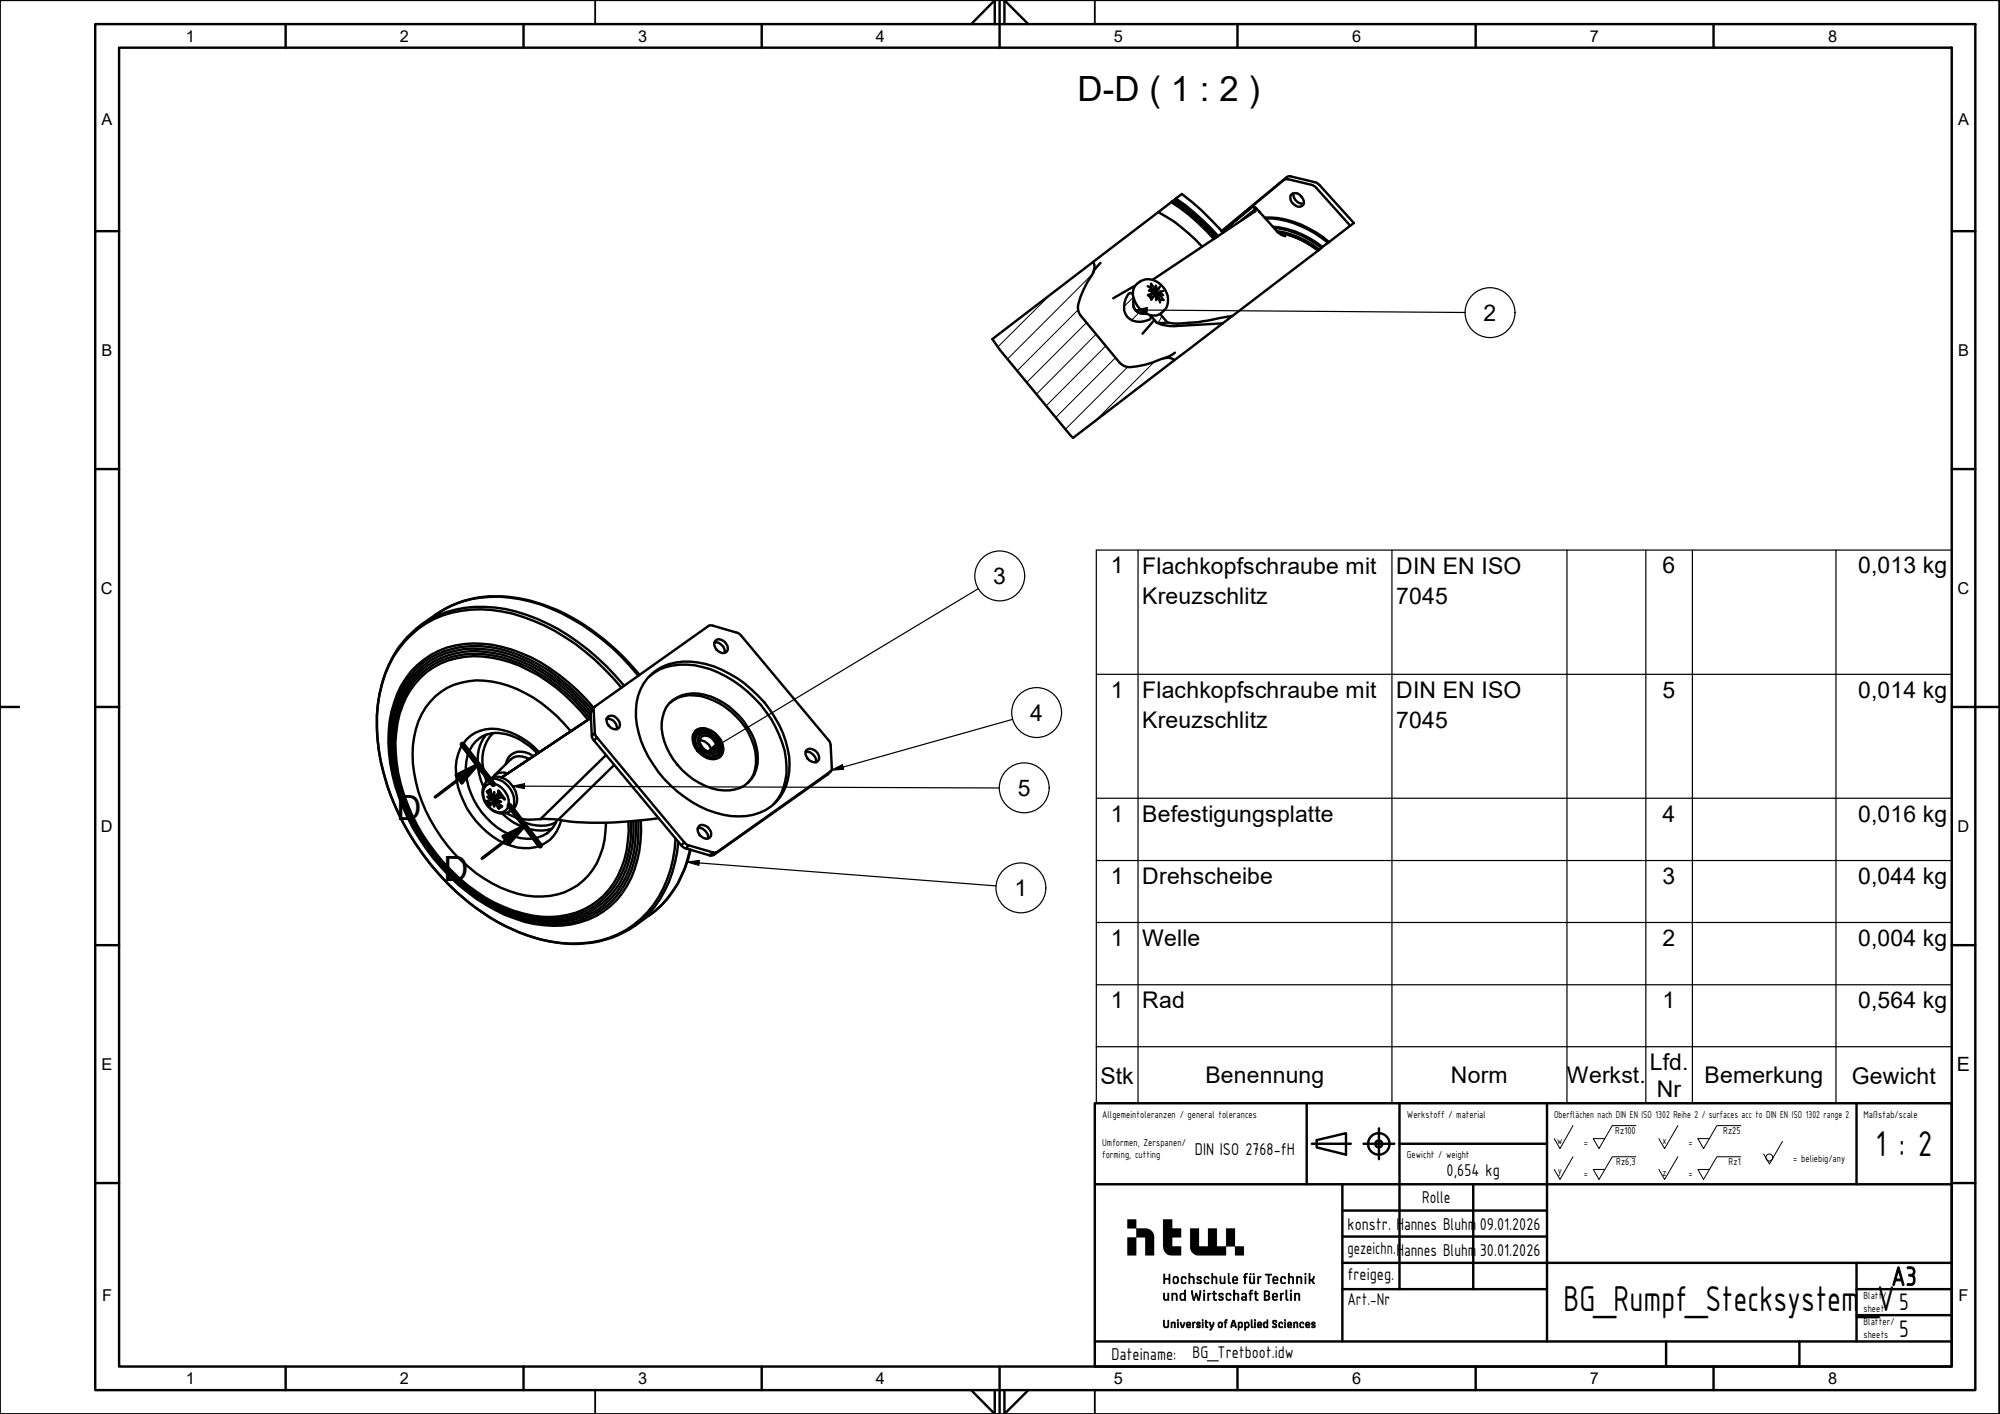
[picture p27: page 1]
Gewicht / weight 0,654 kg; Dateiname: BG_Tretboot.idw

1 | Flachkopfschraube mit Kreuzschlitz | DIN EN ISO 7045 | | 6 | | 0,013 kg

1 | Flachkopfschraube mit Kreuzschlitz | DIN EN ISO 7045 | | 5 | | 0,014 kg

1 | Befestigungsplatte | | | 4 | | 0,016 kg

1 | Drehscheibe | | | 3 | | 0,044 kg

1 | Welle | | | 2 | | 0,004 kg

1 | Rad | | | 1 | | 0,564 kg

Stk | Benennung | Norm | Werkst. | Lfd. Nr | Bemerkung | Gewicht

Allgemeintoleranzen / general tolerances Umformen, Zerspanen/ forming, cutting DIN ISO 2768-fH | | Werkstoff / material | Oberflächen nach DIN EN ISO 1302 Reihe 2 / surfaces acc to DIN EN ISO 1302 range 2 Rz100 Rz25 w = x = = beliebig/any Rz6,3 Rz1 y = z = | Maßstab/scale 1 : 2

Rolle

konstr. | Hannes Bluhm | 09.01.2026
gezeichn. | Hannes Bluhm 30.01.2026
freigeg. | | | BG_Rumpf_Stecksystem_V | A3
Art.-Nr | | | | Blatt/ 5 sheet

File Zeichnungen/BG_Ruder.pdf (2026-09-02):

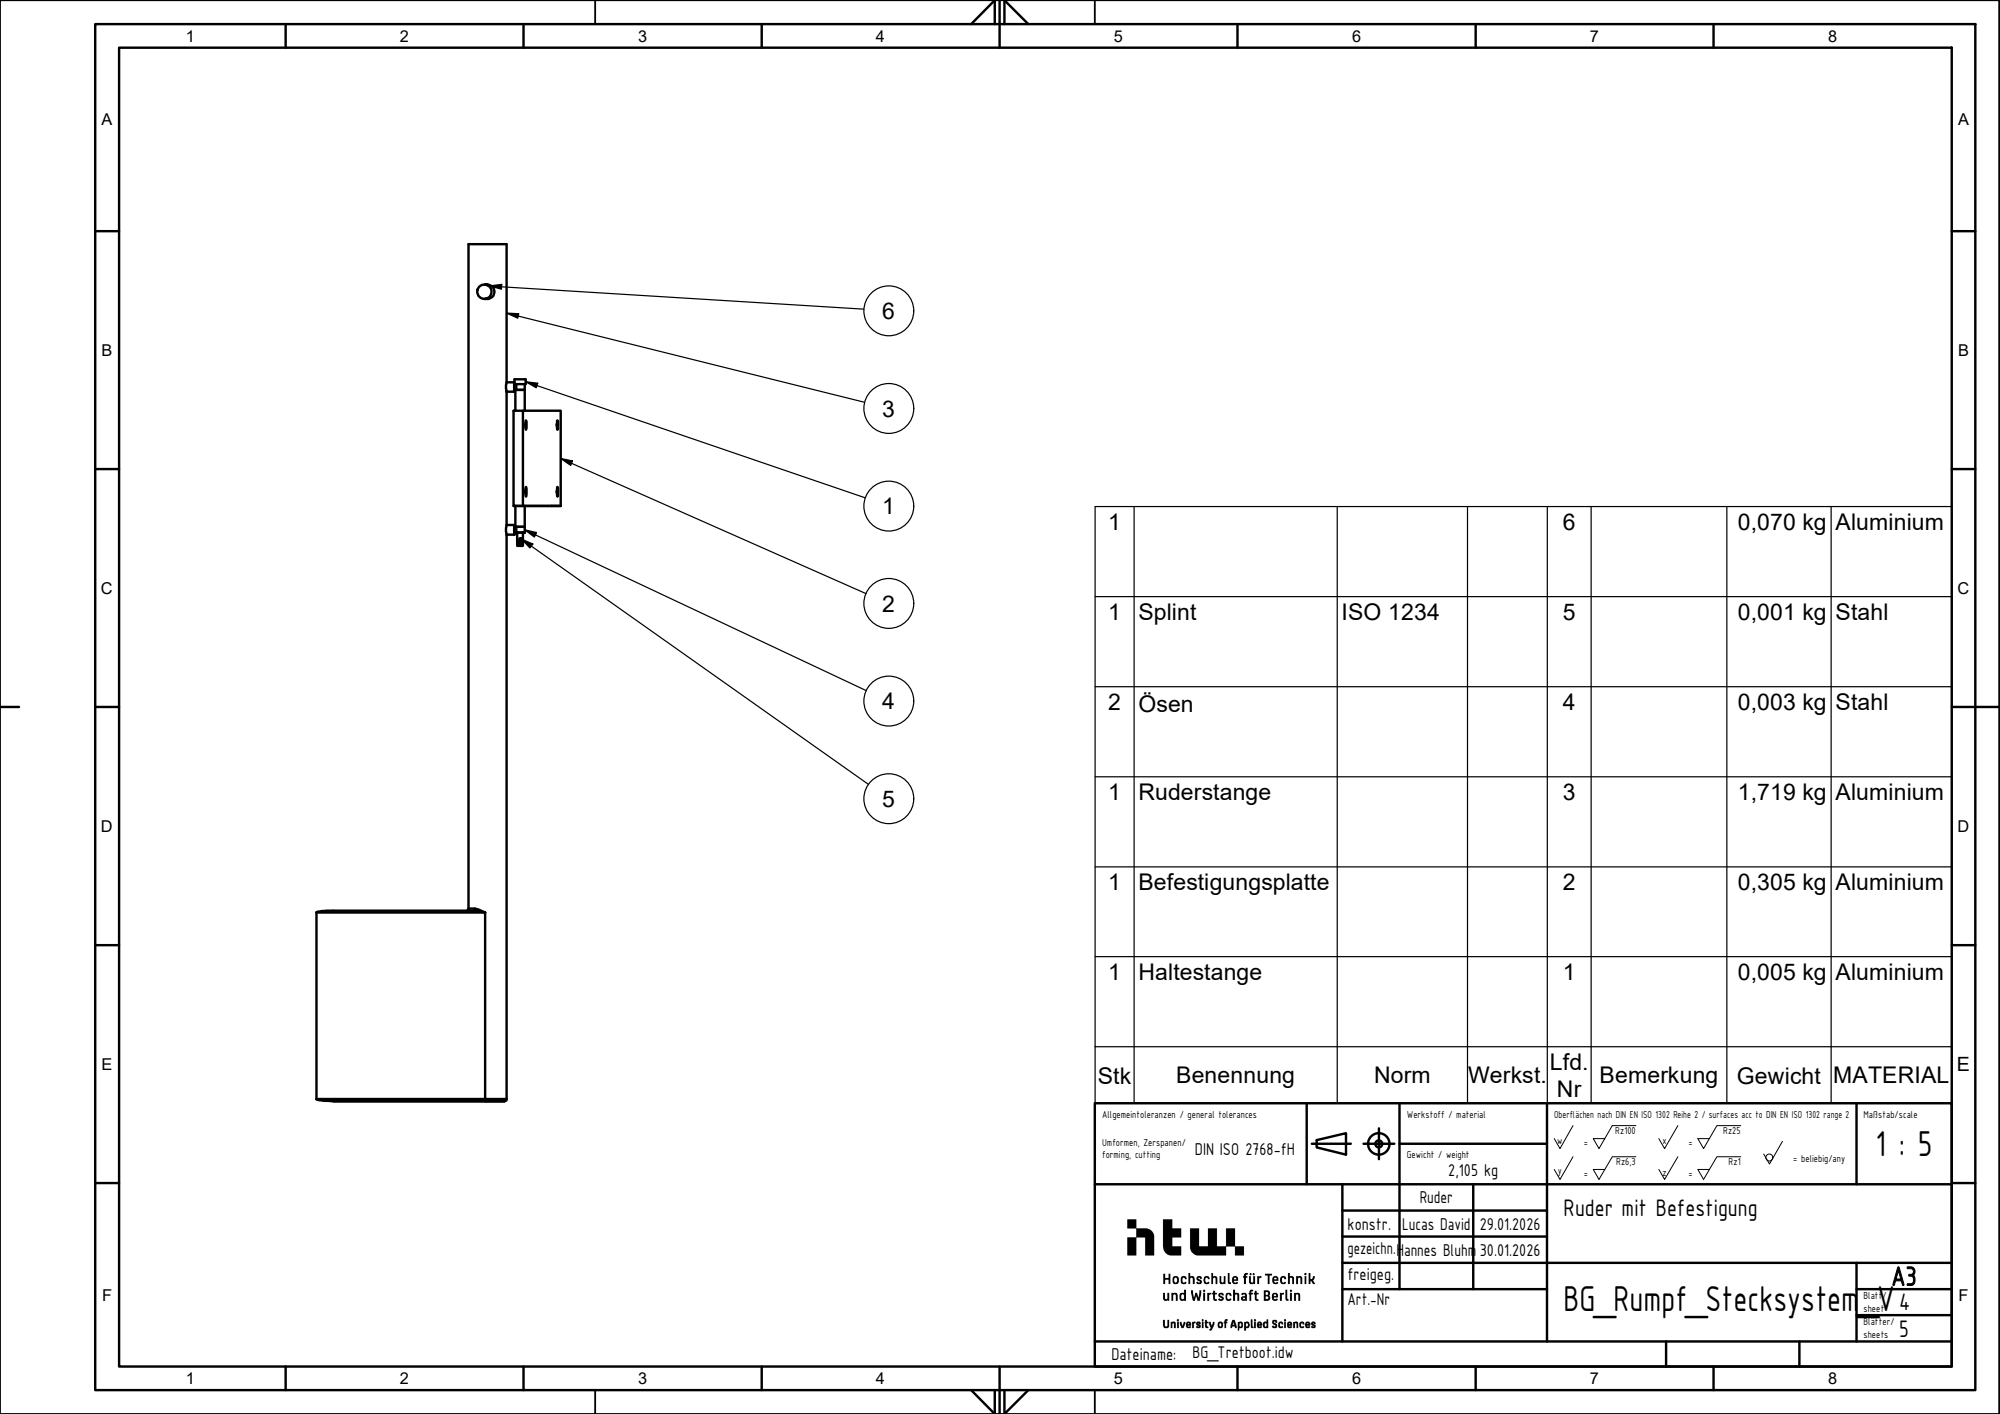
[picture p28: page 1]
Gewicht / weight 2,105 kg; Dateiname: BG_Tretboot.idw

1 | | | | 6 | | 0,070 kg | Aluminium

1 | Splint | ISO 1234 | | 5 | | 0,001 kg | Stahl

2 | Ösen | | | 4 | | 0,003 kg | Stahl

1 | Ruderstange | | | 3 | | 1,719 kg | Aluminium

1 | Befestigungsplatte | | | 2 | | 0,305 kg | Aluminium

1 | Haltestange | | | 1 | | 0,005 kg | Aluminium

Stk | Benennung | Norm | Werkst. | Lfd. Nr | Bemerkung | Gewicht | MATERIAL

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

Ruder | | Ruder mit Befestigung

konstr. | Lucas David | 29.01.2026
gezeichn. | Hannes Bluhm 30.01.2026
freigeg. | | | BG_Rumpf_Stecksystem_V | A3
Art.-Nr | | | | Blatt/ 4 sheet

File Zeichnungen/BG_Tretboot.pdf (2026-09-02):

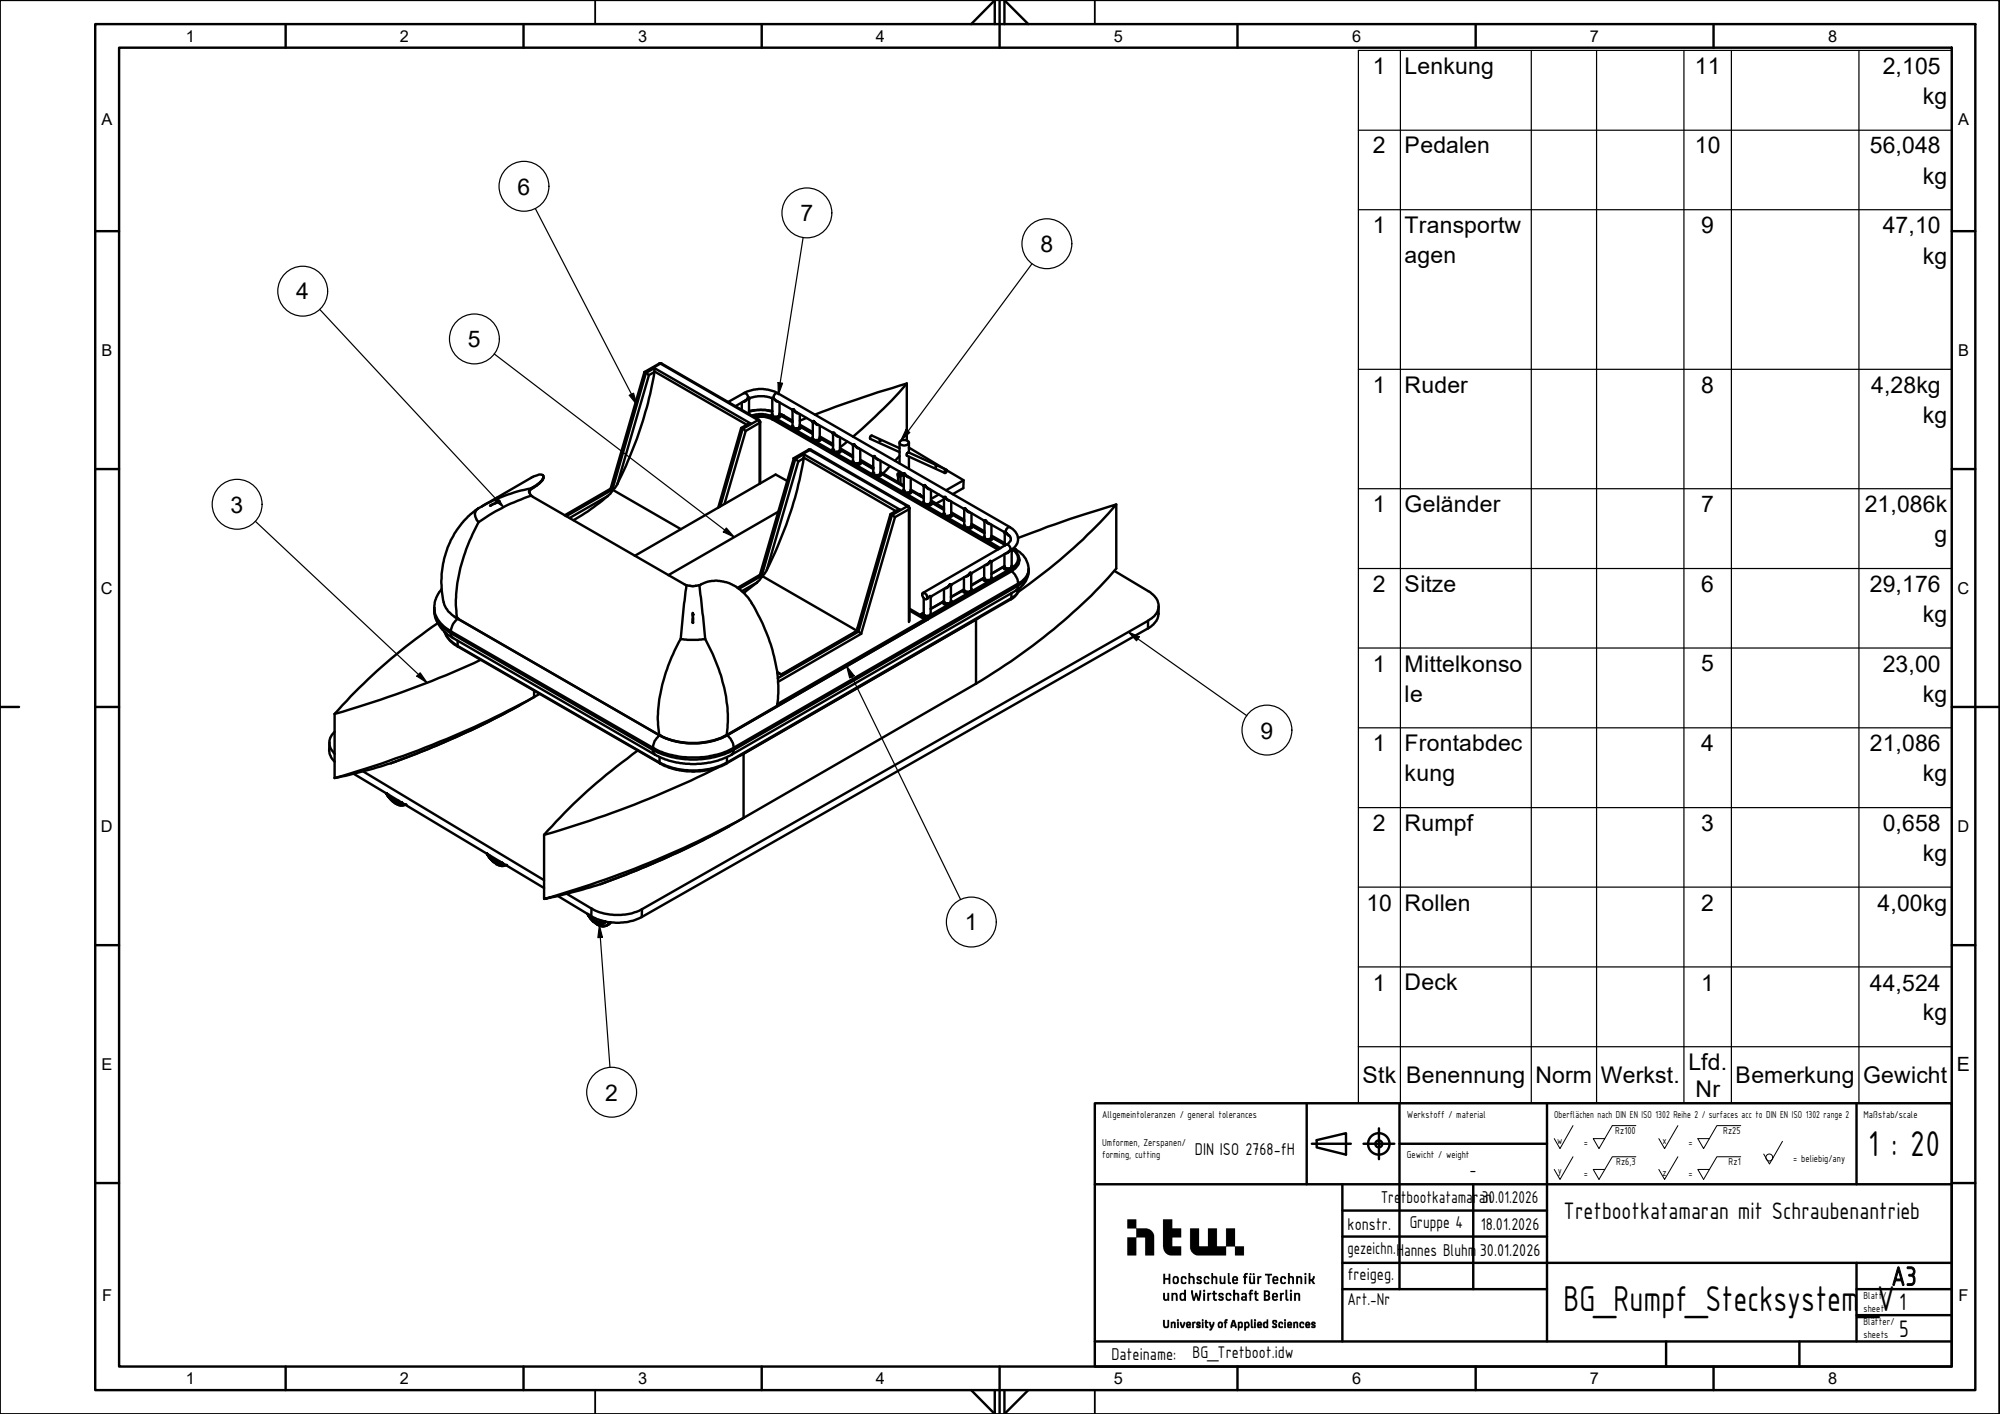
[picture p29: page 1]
t. ABCDEF

2 | P e d ale n | | | 1 0 | | 5 6 , 0 4 8kg

1 | R u d e r | | | 8 | | 4 , 2 8 k gkg

1 | G elä n d e r | | | 7 | | 2 1 , 0 8 6 kg

2 | Sit z e | | | 6 | | 2 9 , 1 7 6kg

1 | Mit t elk o n s o | | | 5 le | | 2 3 , 0 0kg

1 0 | R olle n | | | 2 | | 4 , 0 0 k g

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

r. gezeichn. freigeg. | G H a n n e s B l u h m | 3 0.0 1.2 0 2 6

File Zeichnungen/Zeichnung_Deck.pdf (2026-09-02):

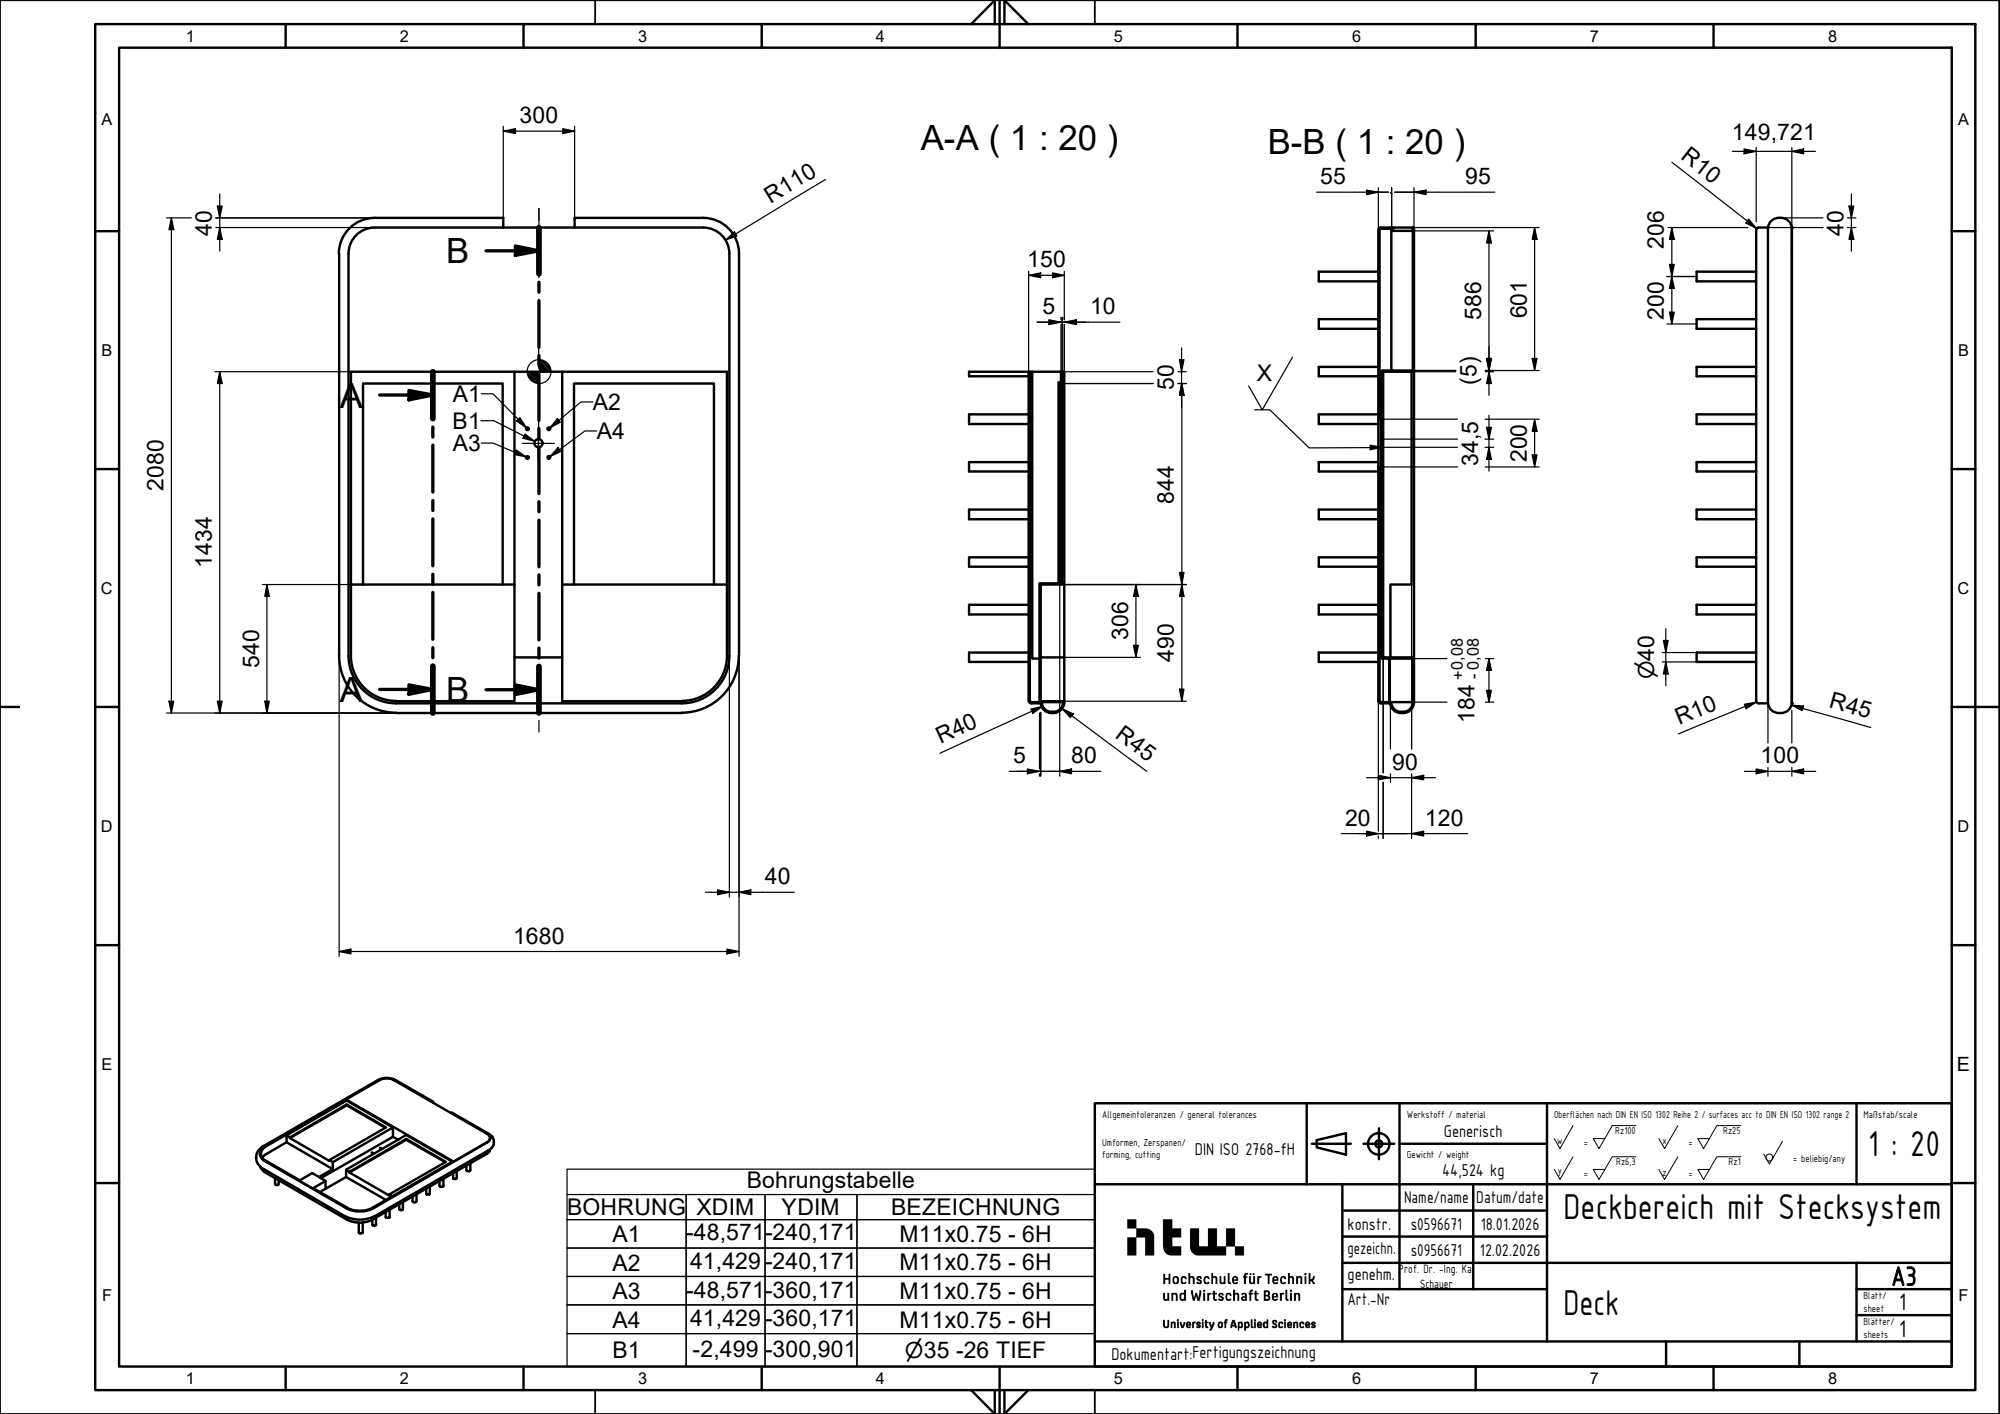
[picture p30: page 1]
Werkstoff / material; Gewicht / weight 44,524 kg; = beliebig/any; Umformen, Zerspanen/; forming, cutting; DIN ISO 2768-fH

Allgemeintoleranzen / general tolerances

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

BOHRUNG | XDIM | YDIM | BEZEICHNUNG
A1 | -48,571-240,171 | | M11x0.75 - 6H
A2 | 41,429 -240,171 | | M11x0.75 - 6H
A3 | -48,571-360,171 | | M11x0.75 - 6H
A4 | 41,429 -360,171 | | M11x0.75 - 6H
B1 | -2,499 | -300,901 | ⌀35 -26 TIEF

Name/name | Datum/date | Deckbereich mit Stecksystem

konstr. | s0596671 | 18.01.2026
gezeichn. | s0956671 | 12.02.2026
genehm. | Prof. Dr. -Ing. Kai Schauer | | Deck | A3
Art.-Nr | | | | Blatt/ 1 sheet

Dokumentart:Fertigungszeichnung

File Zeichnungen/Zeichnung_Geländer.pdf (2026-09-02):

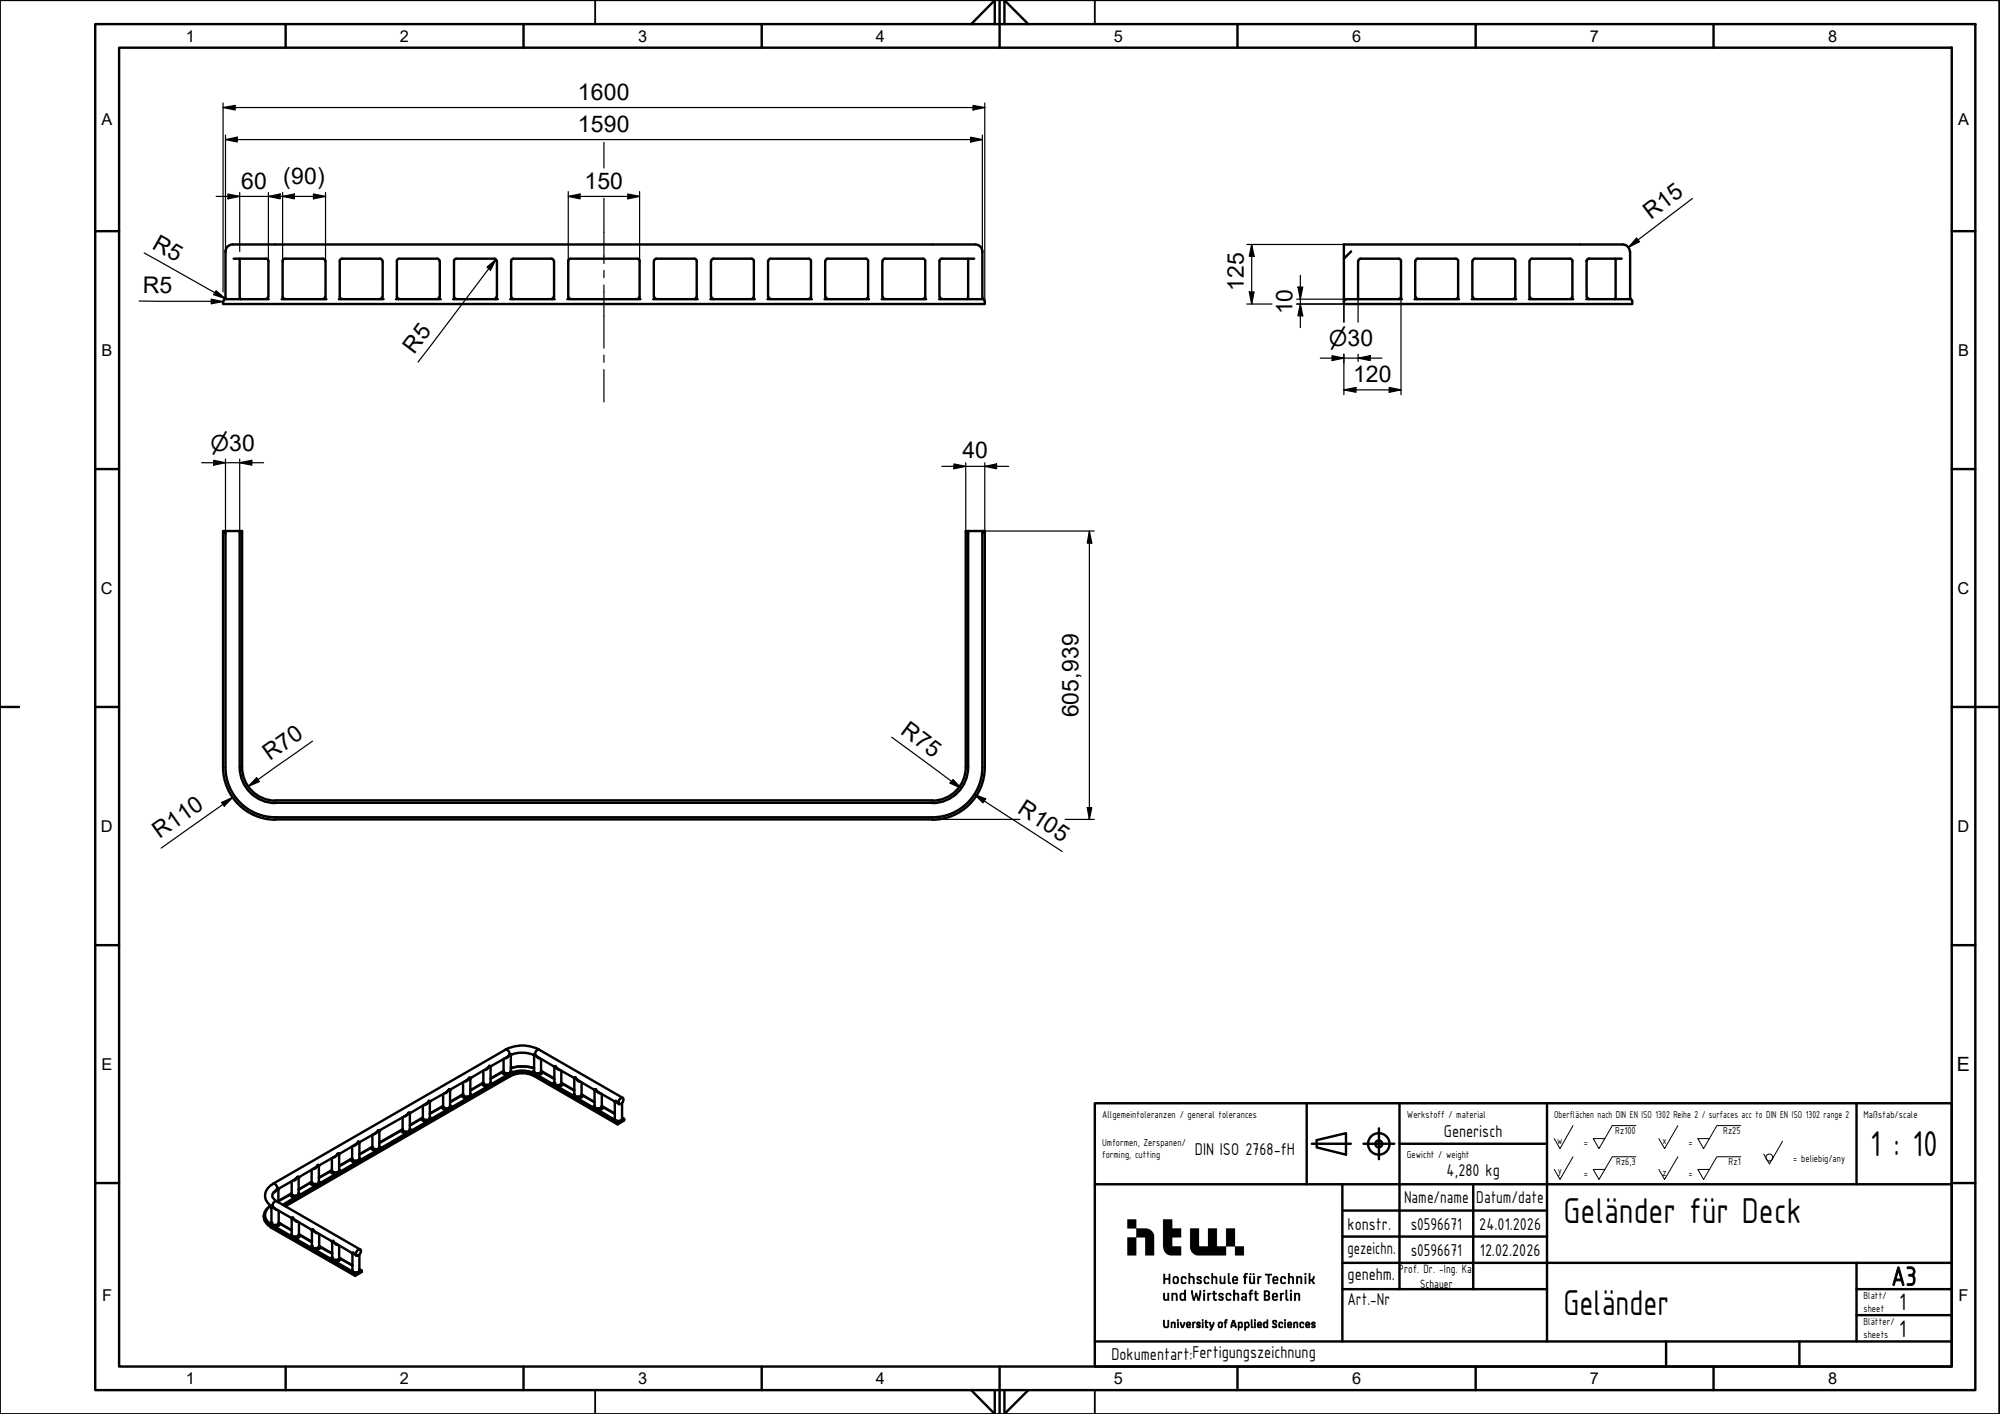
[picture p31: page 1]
Werkstoff / material; Gewicht / weight 4,280 kg; = beliebig/any; Umformen, Zerspanen/; forming, cutting; DIN ISO 2768-fH

Allgemeintoleranzen / general tolerances

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

Name/name | Datum/date | Geländer für Deck

konstr. | s0596671 | 24.01.2026
gezeichn. | s0596671 | 12.02.2026
genehm. | Prof. Dr. -Ing. Kai Schauer | | Geländer | A3
Art.-Nr | | | | Blatt/ 1 sheet

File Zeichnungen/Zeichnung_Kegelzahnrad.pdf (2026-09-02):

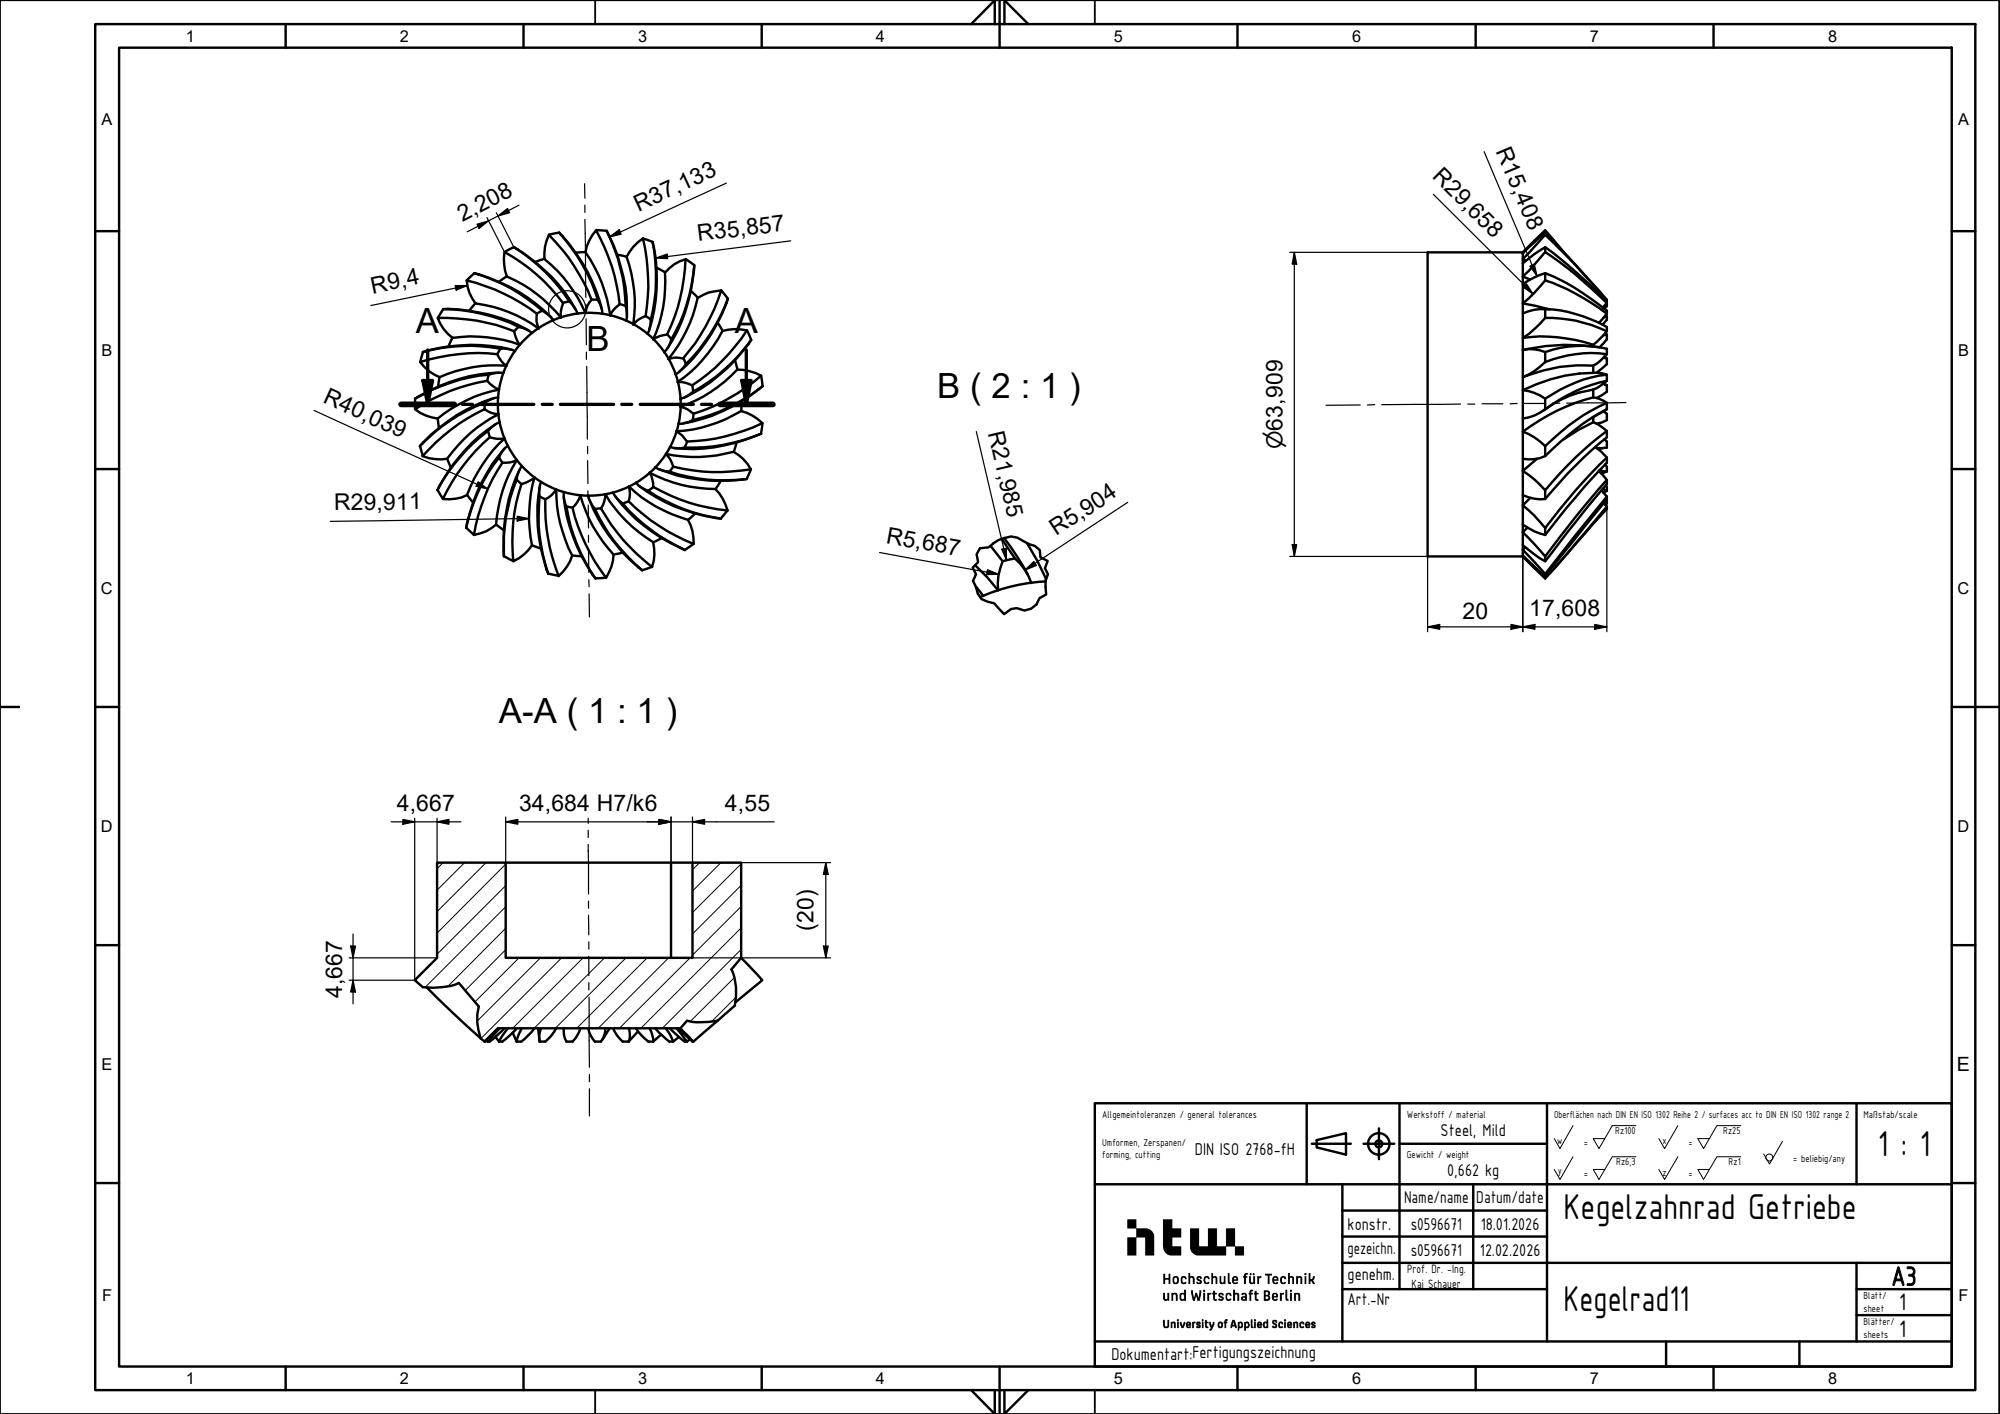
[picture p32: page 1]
Steel, Mild; Werkstoff / material; Gewicht / weight 0,662 kg; = beliebig/any; Umformen, Zerspanen/; forming, cutting; DIN ISO 2768-fH

Allgemeintoleranzen / general tolerances

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

Name/name | Datum/date | Kegelzahnrad Getriebe

konstr. | s0596671 | 18.01.2026
gezeichn. | s0596671 | 12.02.2026
genehm. | Prof. Dr. -Ing. Kai Schauer | | Kegelrad11 | A3
Art.-Nr | | | | Blatt/ 1 sheet

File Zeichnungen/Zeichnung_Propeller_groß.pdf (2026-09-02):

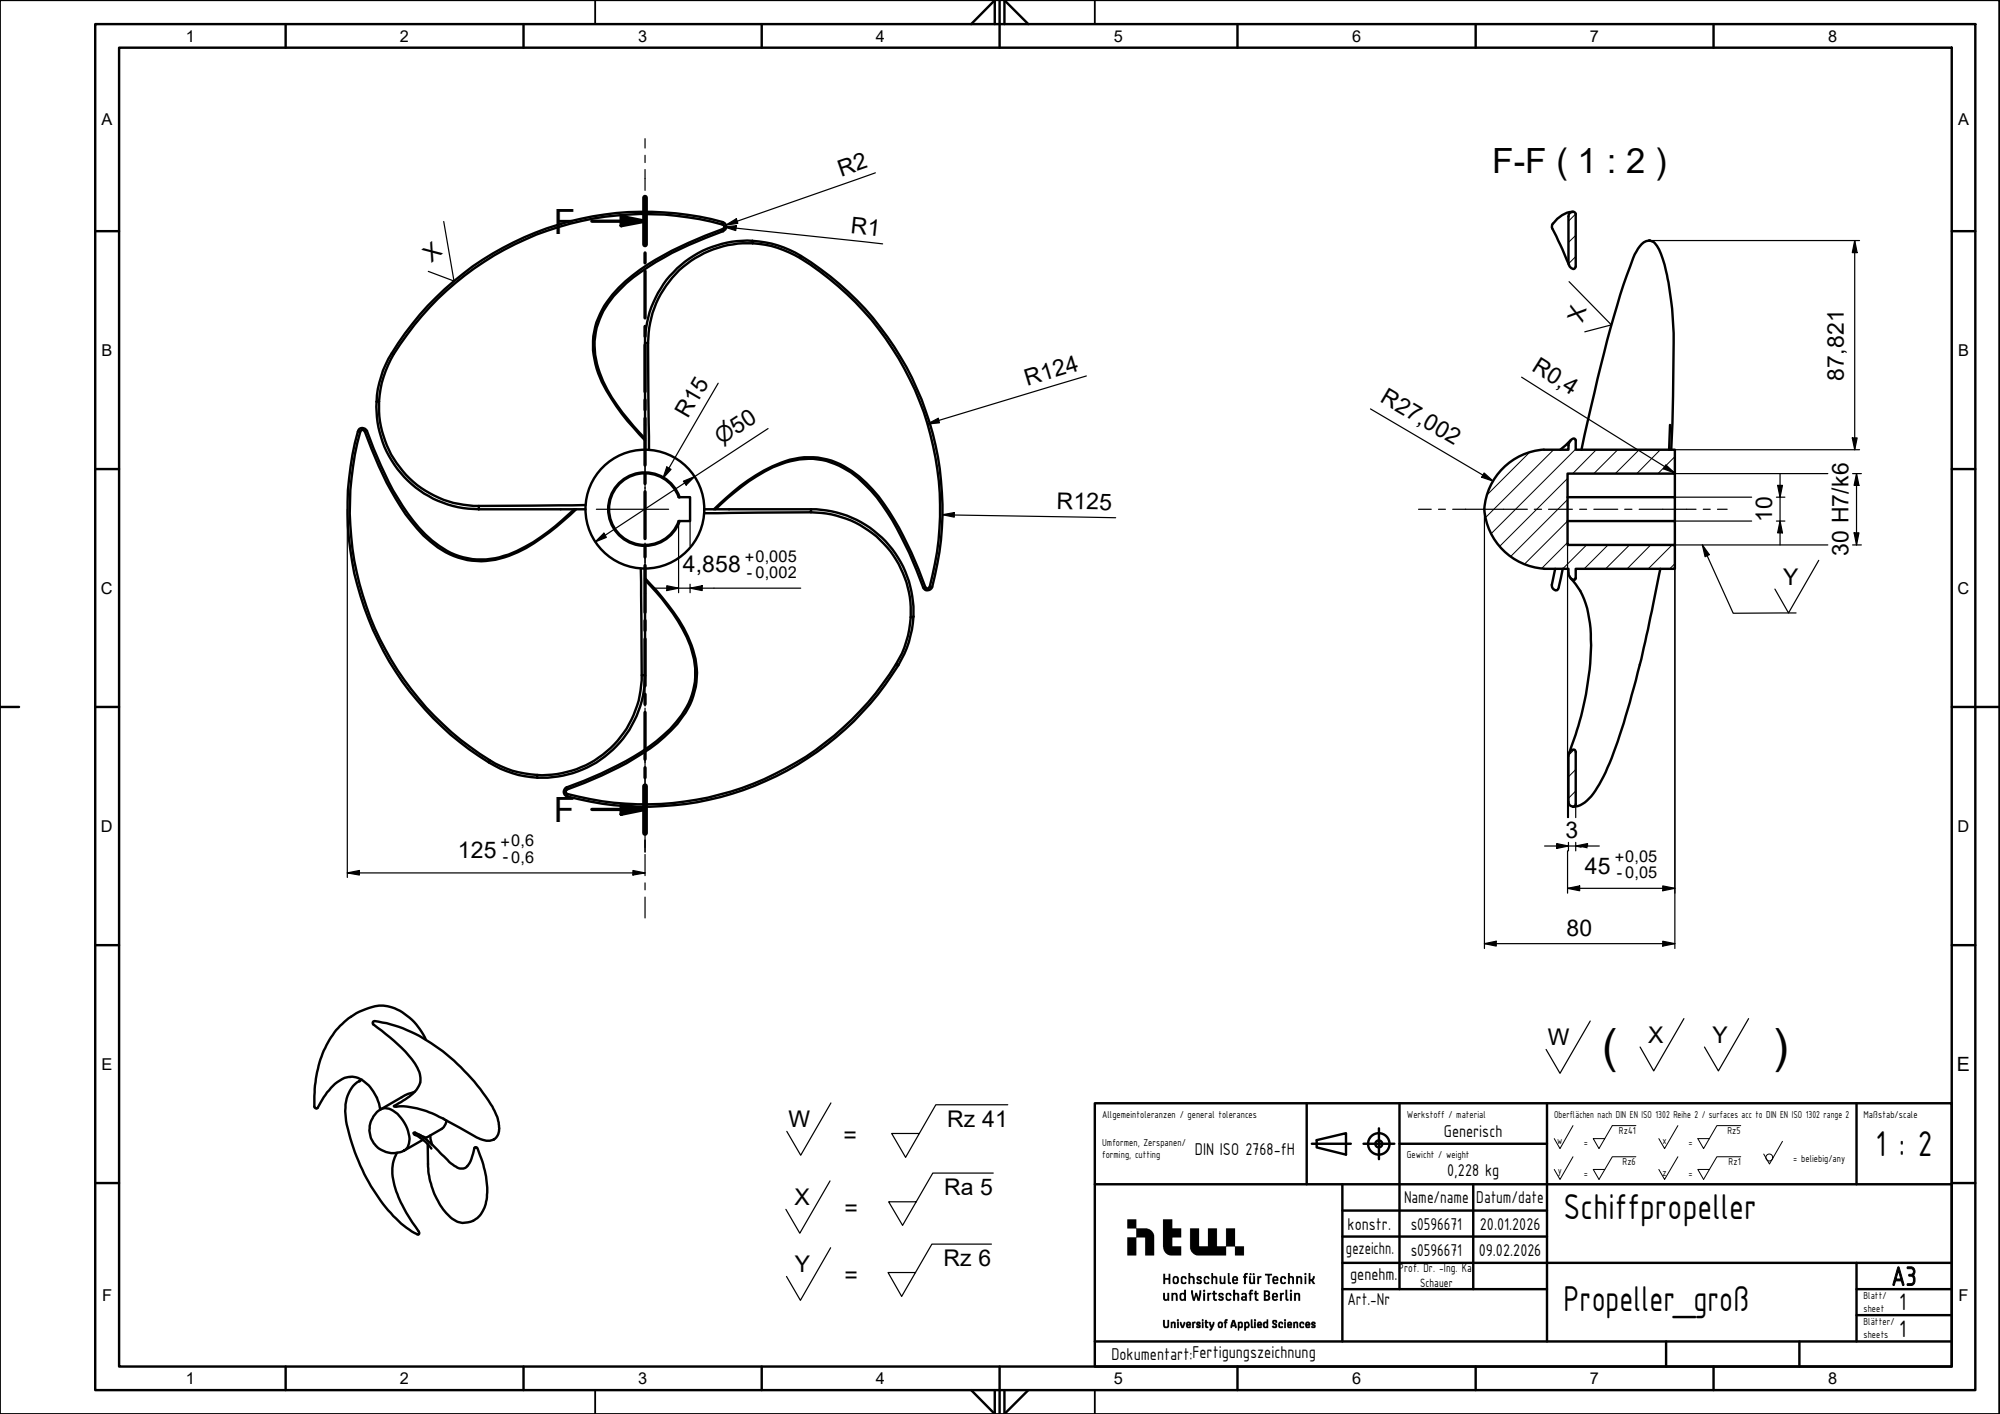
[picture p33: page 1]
Werkstoff / material; Gewicht / weight 0,228 kg; = beliebig/any; Umformen, Zerspanen/; forming, cutting; DIN ISO 2768-fH

Allgemeintoleranzen / general tolerances

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

Name/name | Datum/date | Schiffpropeller

konstr. | s0596671 | 20.01.2026
gezeichn. | s0596671 | 09.02.2026
genehm. | Prof. Dr. -Ing. Kai Schauer | | Propeller_groß | A3
Art.-Nr | | | | Blatt/ 1 sheet

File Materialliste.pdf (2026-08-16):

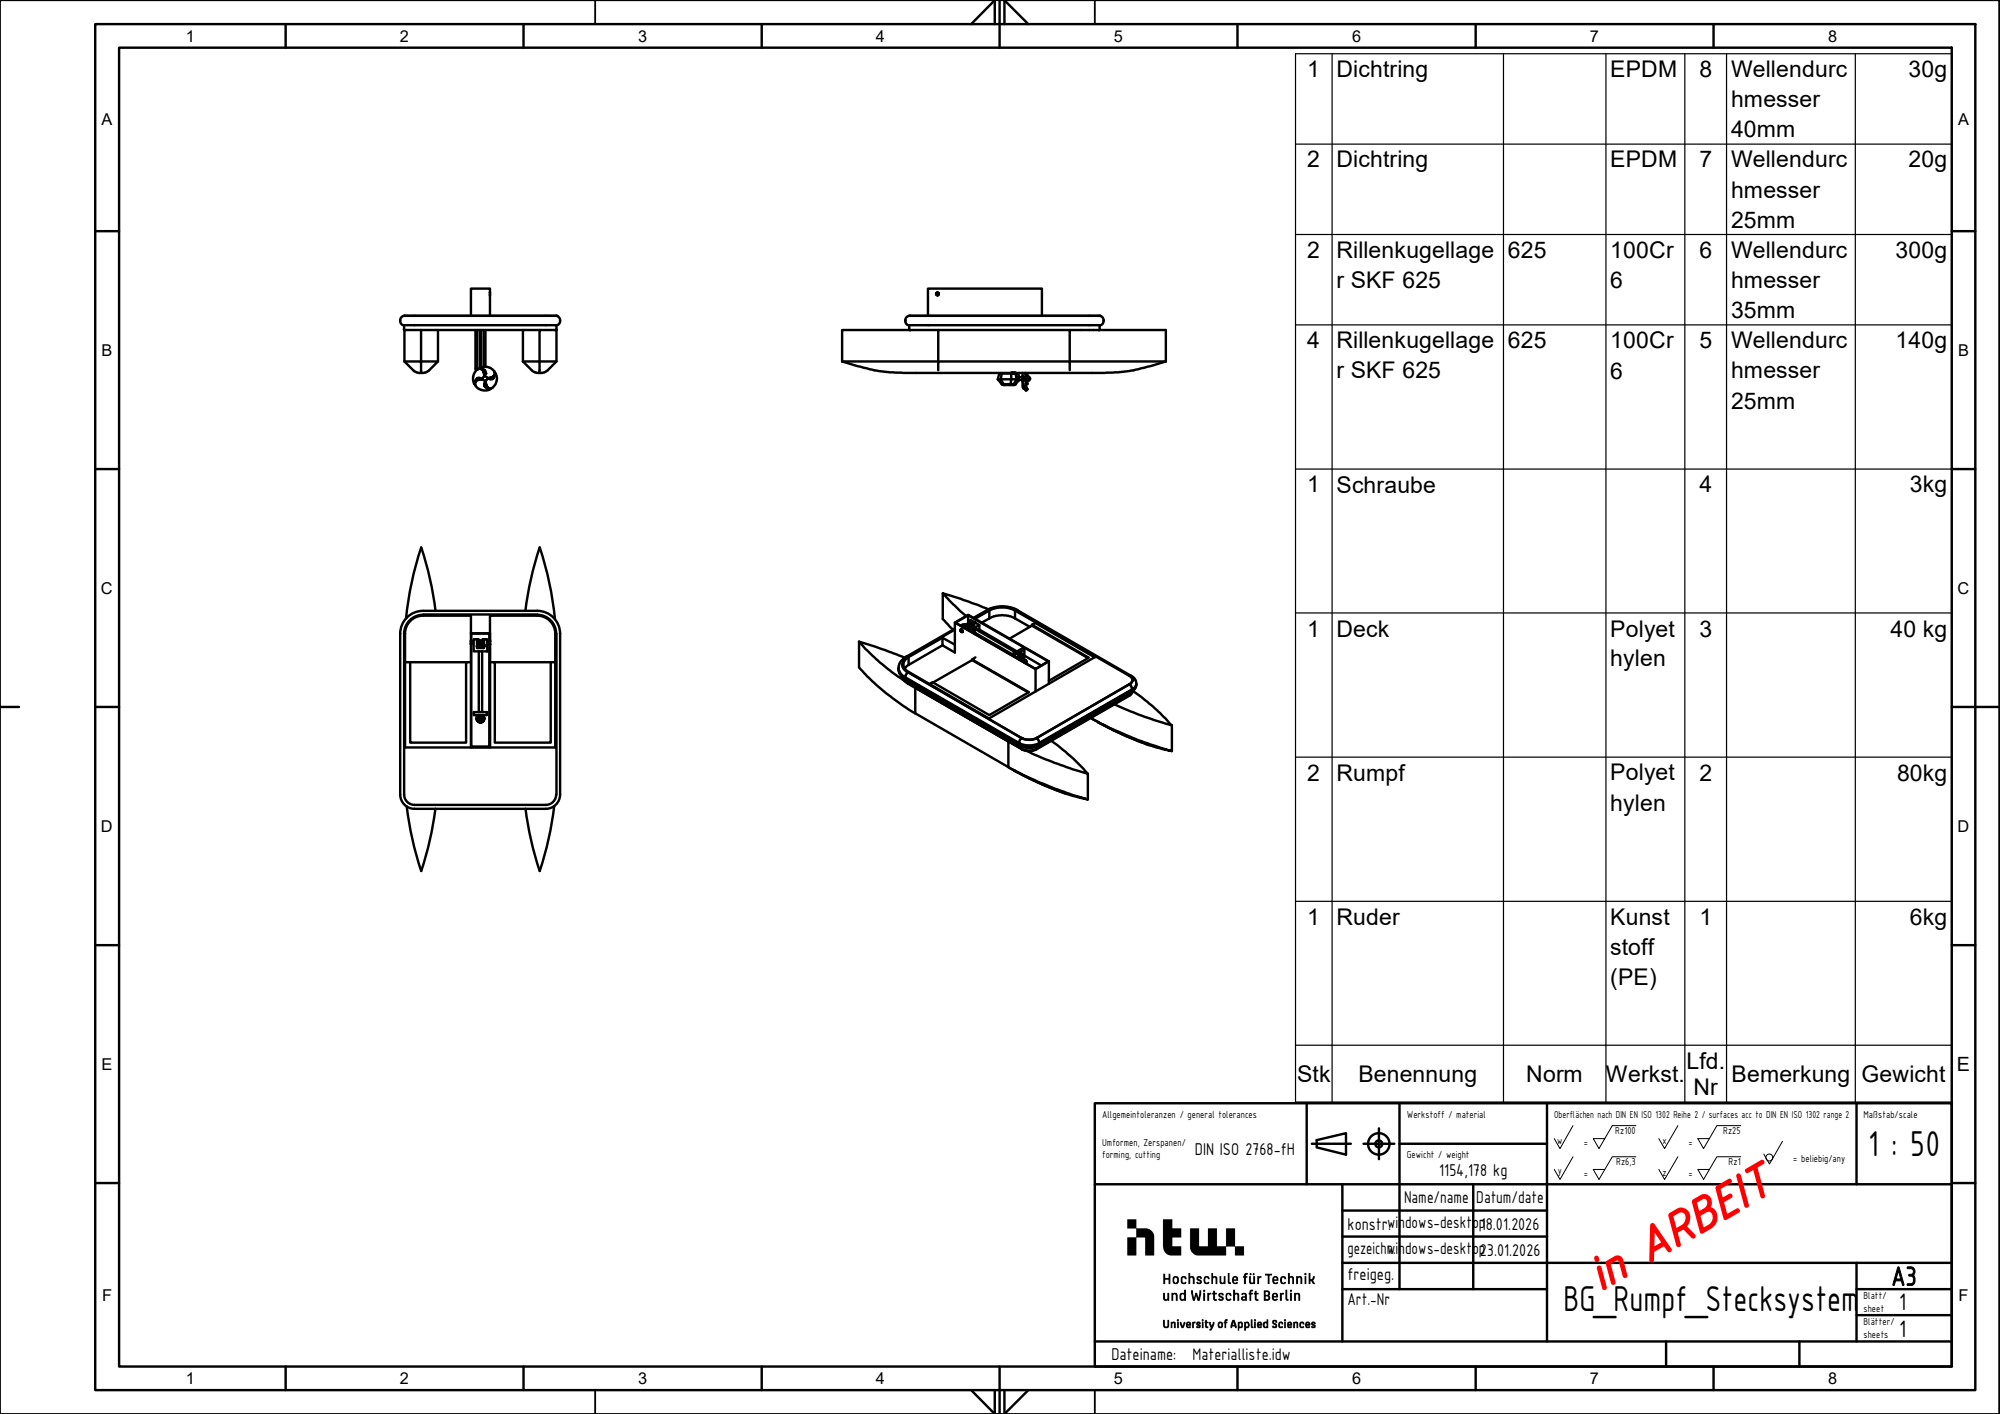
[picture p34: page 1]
t. ABCDEF; in ARBEIT

1 | Dic h t rin g | | E P D M | 8 | W elle n d u r c h m e s s e r 4 0 m m | 3 0 g

2 | Dic h t rin g | | E P D M | 7 | W elle n d u r c h m e s s e r 2 5 m m | 2 0 g

2 | Rille n k u g ella g e r S K F 6 2 5 | 6 2 5 | 1 0 0 C r 6 | 6 | W elle n d u r c h m e s s e r 3 5 m m | 3 0 0 g

41 | Rille n k u g ella g e r S K F 6 2 5 S c h r a u b e | 6 2 5 | 1 0 0 C r 6 | 5 4 | W elle n d u r c h m e s s e r 2 5 m m | 1 4 0 g 3 k g

1 | D e c k | | P oly e t h yle n | 3 | | 4 0 k g

2 | R u m p f | | P oly e t h yle n | 2 | | 8 0 k g

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

r. gezeichn. freigeg.win win | d o w s -d e s k t | o p2 3.0 1.2 0 2 6

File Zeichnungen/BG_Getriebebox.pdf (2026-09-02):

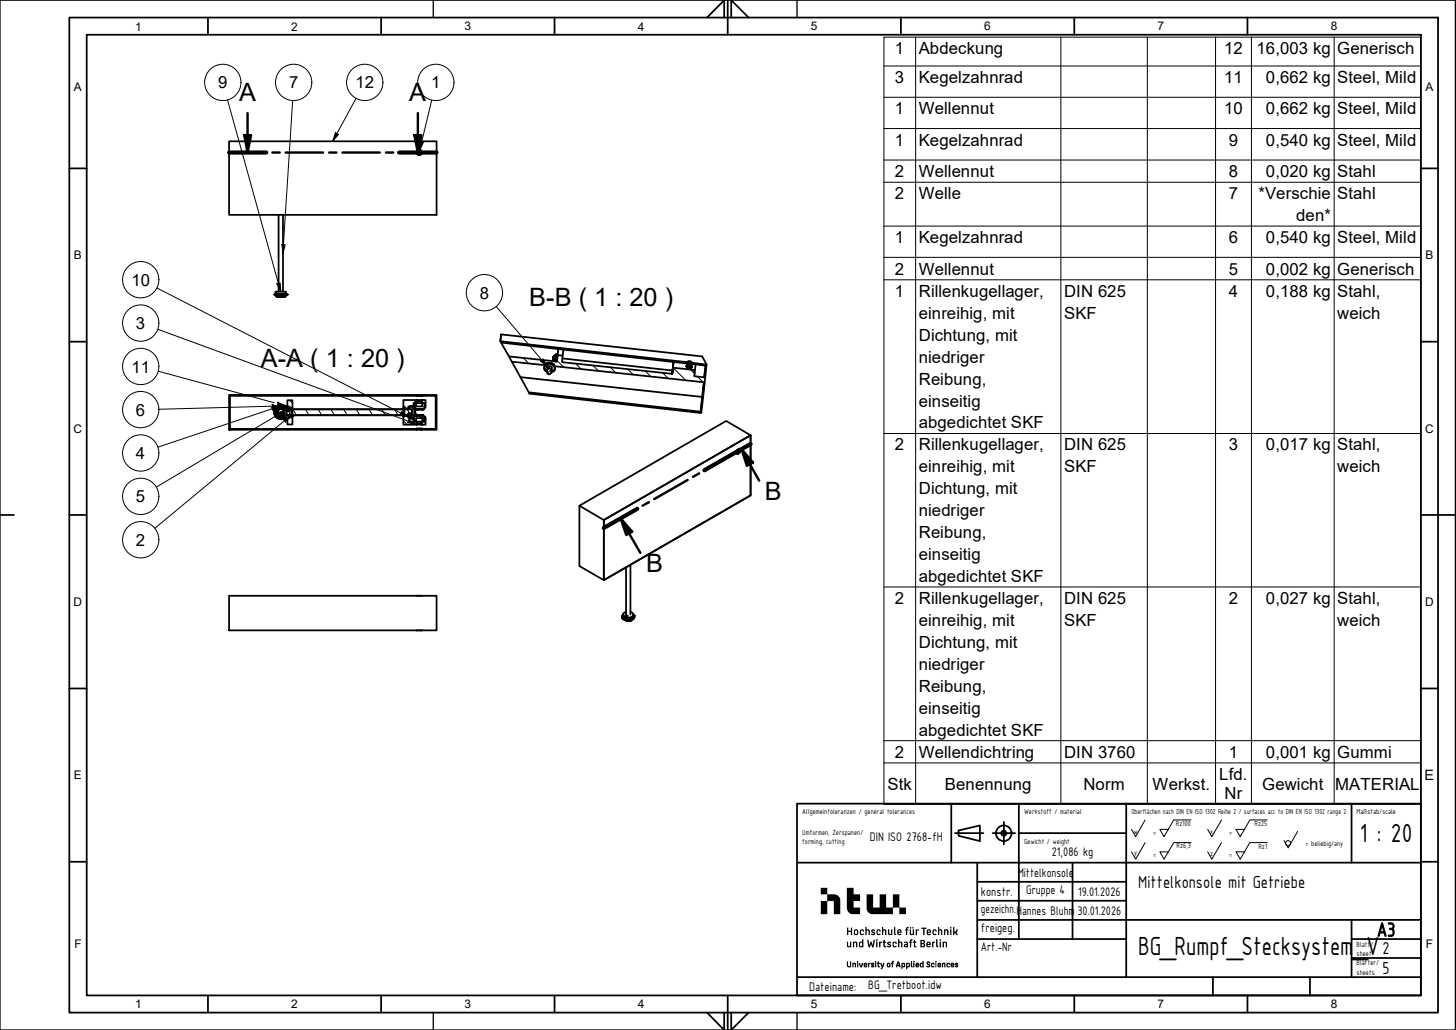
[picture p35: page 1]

1 | A b d e c k u n g | | | 1 2 | 1 6 , 0 0 3 k g | G e n e ris c h
3 | K e g elz a h n r a d | | | 1 1 | 0 , 6 6 2 k g | S t e el, Mild

1 | W elle n n u t | | | 1 0 | 0 , 6 6 2 k g | S t e el, Mild

1 | K e g elz a h n r a d | | | 9 | 0 , 5 4 0 k g | S t e el, Mild

2 | W elle n n u t | | | 8 | 0 , 0 2 0 k g | S t a

2 | W elle | | | 7 | | Stahl den* hl *Verschie

1 | K e g elz a h n r a d | | | 6 | 0 , 5 4 0 k g | S t e el, Mild

2 | W elle n n u t | | | 5 | 0 , 0 0 2 k g | G e n e ris c h
1 | Rille n k u g ella g e r , ein r eihig , mit Dic h t u n g , mit nie d rig e r R eib u n g , ein s eitig a b g e dic h t e t S K F | DIN 6 2 5 S K F | | 4 | 0 , 1 8 8 k g | S t a hl, w eic h

2 | Rille n k u g ella g e r , ein r eihig , mit Dic h t u n g , mit nie d rig e r R eib u n g , ein s eitig a b g e dic h t e t S K F | DIN 6 2 5 S K F | | 3 | 0 , 0 1 7 k g | S t a hl, w eic h

22 | Rille n k u g ella g e r , ein r eihig , mit Dic h t u n g , mit nie d rig e r R eib u n g , ein s eitig a b g e dic h t e t S K F | DIN 6 2 5 S K F | | 2 | 0 , 0 2 7 k g | S t a hl, w eic h

W elle n dic h t rin g | DIN 3 7 6 0 | | 1 | 0 , 0 0 1 k g | MATERIA G u m mi Gewicht
S t k | B e n e n n u n g | N o r m | W e r k s | L f d. Nr | | L

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

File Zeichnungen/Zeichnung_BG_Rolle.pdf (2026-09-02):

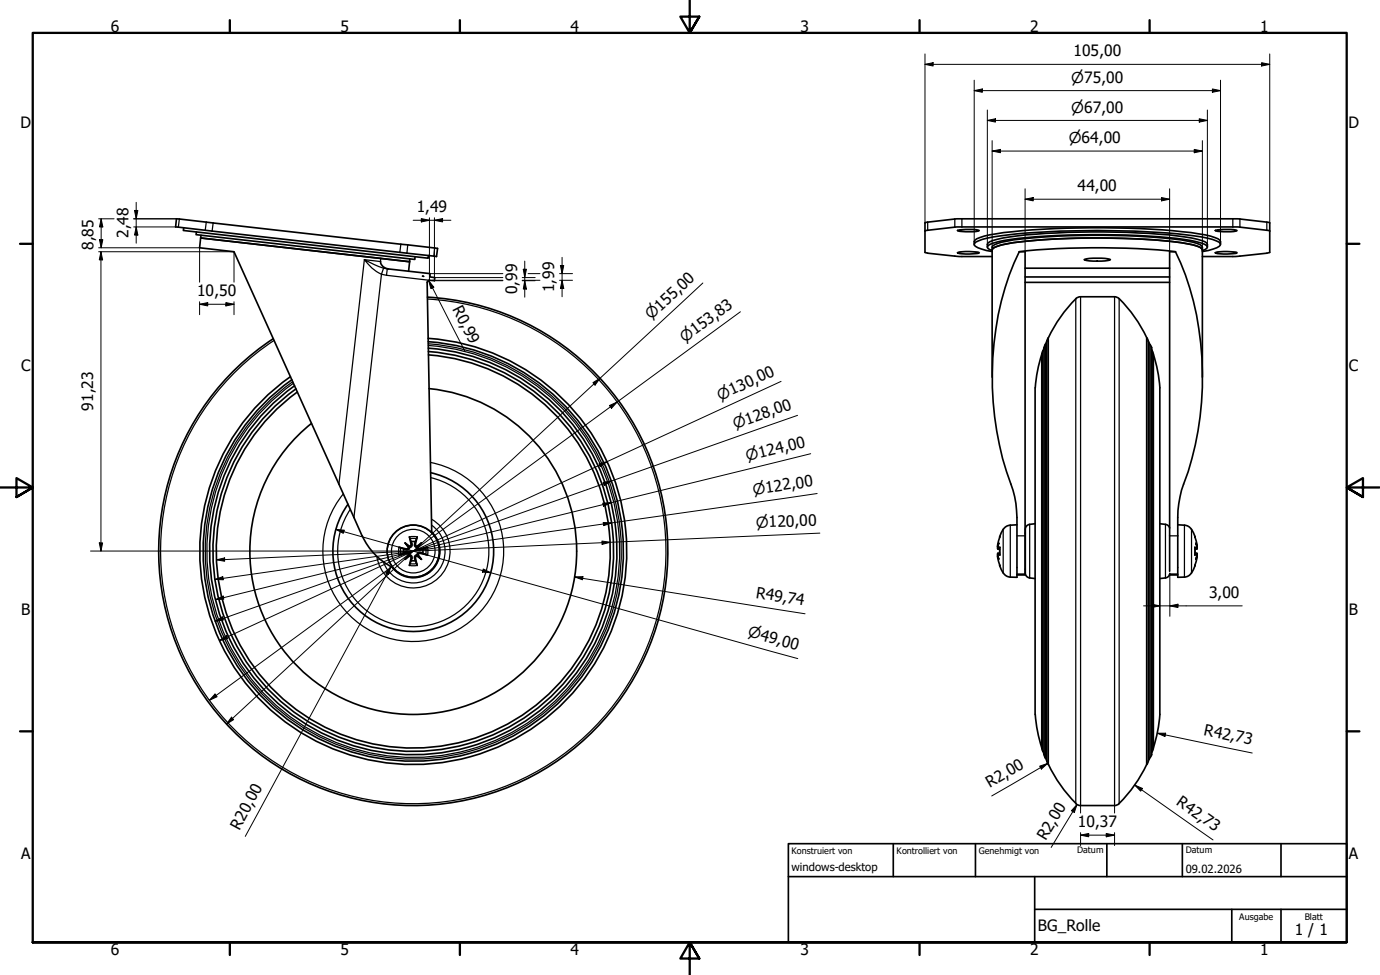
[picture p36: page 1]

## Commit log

2026-09-02 Update README with project details and assembly notes
    Clarified the description of the construction project and noted that assembly opening is currently only possible via Inventor (AutoCAD).
2026-09-02 added step files for generell avaibility
    [Außenrumpf_schnittig.stp, Bolzen_fuer_Ruder.stp, Frontabdeckung.stp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]
